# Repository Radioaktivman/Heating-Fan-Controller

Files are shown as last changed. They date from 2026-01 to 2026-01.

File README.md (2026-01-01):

# Heating Fan Controller

A temperature-controlled fan system for improving radiator efficiency through forced convection.

## Overview

This project provides an automated control system for heating radiator fans. By using forced convection, it significantly improves the heat output and efficiency of traditional radiators, especially at lower flow temperatures. This is particularly beneficial for heat pump systems that operate more efficiently at lower temperatures.

## Features

- **Temperature-Based Control**: Automatically activates fans based on radiator temperature
- **PWM Fan Control**: Smooth and quiet fan speed regulation
- **Efficient Heat Distribution**: Improves radiator efficiency and room heating
- **Low Noise Operation**: Designed for quiet residential use

## Why Use Radiator Fans?

Classical radiators typically require high flow temperatures to effectively heat a room. Adding forced convection with PC fans can:

- Significantly enhance radiator efficiency at low flow temperatures
- Enable heat pumps to operate at optimal (lower) temperatures
- Reduce heating costs while maintaining comfort
- Improve heat distribution in the room

### Advanced Monitoring and Control

With four temperature sensors, this controller provides comprehensive monitoring of the entire heating cycle:

- **Flow/Return Temperature Monitoring**: Track the temperature difference across the radiator to measure heat transfer efficiency
- **Air Temperature Delta**: Measure the temperature increase from inlet (bottom) to outlet (top) to quantify the actual heating effect
- **Performance Optimization**: Automatically adjust fan speed based on the temperature differentials to maximize efficiency
- **System Diagnostics**: Identify issues like poor circulation, air locks, or insufficient flow temperatures
- **Energy Efficiency**: Calculate the actual heat output and optimize fan operation to minimize electricity consumption while maximizing heat distribution

## Hardware Components

### Required Components
- **ESP Heating Controller PCB** (Rev 1.0 - design files in `/PCB` folder)
  - PCBs available from maintainer (contact via PM)
  - [3D-printable housing available on Thingiverse](https://www.thingiverse.com/thing:7254499)
- Temperature sensors: DS18B20 (up to 4 sensors supported)
- **12V PC fans** - Both 3-pin and 4-pin fans  up to 6 fans total
  - 3-pin fans: Standard DC voltage control
  - 4-pin PWM fans: Precise PWM speed control (recommended for quieter operation)
  - Note: All fans operate at the same speed (shared PWM signal)
- 12V power supply 
- **[3D-printed mounting clips](https://www.thingiverse.com/thing:5943925)** for attaching fans to radiators 

### Recommended Fans
High-quality PC fans operating at low speeds (<500 RPM) are essentially inaudible while providing significant heat output improvement. The controller supports both 3-pin and 4-pin fans.

## PCB Design

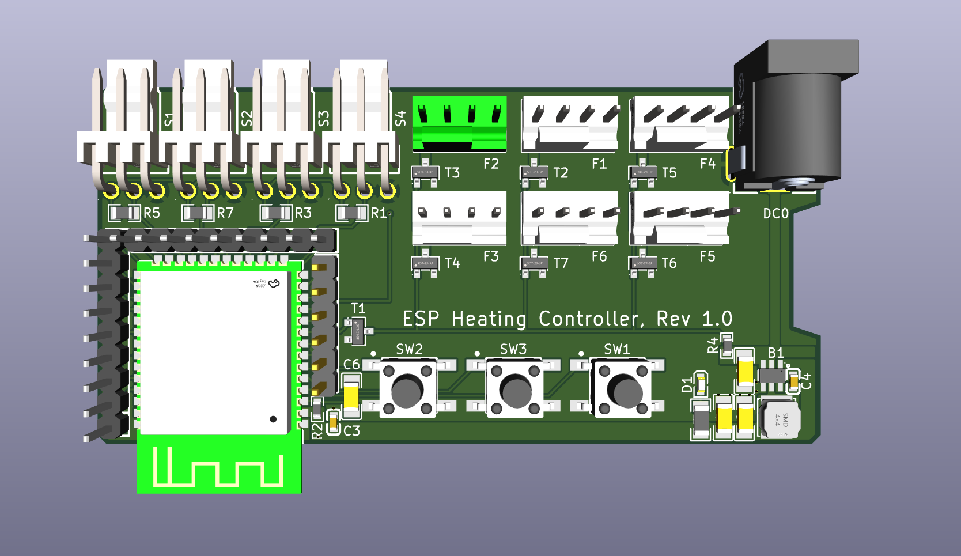
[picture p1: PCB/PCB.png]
ESP Heating Controller PCB

*ESP Heating Controller Rev 1.0 by 2SimpleEnergy GmbH*

The `/PCB` folder contains the custom PCB design files for this project. 

### Hardware Specifications

**Microcontroller:**
- ESP32-WROOM module (WiFi/Bluetooth enabled)
- Enables smart home integration and remote monitoring

**Fan Outputs:**
- **6 fan output channels** (F1-F6)
- **All channels share the same PWM control signal** - fans operate synchronously at the same speed
- Supports multiple fans or fan groups connected across the 6 outputs
- **Compatible with both 3-pin and 4-pin PC fans:**
  - **3-pin fans**: Standard DC voltage control (full voltage = full speed)
  - **4-pin PWM fans**: Advanced PWM control with tachometer feedback for precise speed regulation and RPM monitoring
- Standard 4-pin fan connectors for easy plug-and-play installation

**Temperature Sensor Inputs:**
- **3 Pin Connector ** (S1-S4) for DS18B20 or similar sensors
- Designed for comprehensive heating system monitoring:
  - **Flow temperature**: Monitor water entering the radiator
  - **Return flow temperature**: Monitor water leaving the radiator
  - **Air inlet temperature**: Measure air temperature at bottom of radiator (before heating)
  - **Air outlet temperature**: Measure air temperature at top of radiator (after heating)
- Pull-up resistors (R1, R3, R5, R7) integrated on board
- Enables precise control based on actual radiator performance and efficiency calculations

**User Interface:**
- 3 tactile buttons (SW1, SW2, SW3) for manual control and configuration
- Status LED indicators

**Power Supply:**
- DC barrel jack connector (DC0) for 12V input
- Onboard voltage regulation for ESP32 (3.3V)

**PCB Housing:**
A 3D-printable housing for this PCB is available on Thingiverse for protection and professional mounting:
👉 **[ESP Heating Controller PCB Housing](https://www.thingiverse.com/thing:7254499)**

**PCB Availability:**
I have some leftover PCBs ! If you're interested in procuring a board instead of manufacturing it yourself, please contact me via private message on GitHub.

## Installation

### Hardware Setup

1. **3D-print the components**:
   - Download and print the **[PCB housing](https://www.thingiverse.com/thing:7254499)** for the controller
   - Download and print the **[fan mounting clips](https://www.thingiverse.com/thing:5943925)** (2 clips per fan)
2. **Assemble the controller**:
   - Install the ESP Heating Controller PCB into the housing
   - Mount the housing to wall or heating
3. **Prepare the fans**: Mount the PC fans using the printed clips below your radiators
   - Insert clips from below between the radiator ribs
   - Ensure secure fit (designed for 75mm inner distance, adjustable)
   - Use cable ties through the eyelets for cable management
3. **Wire the temperature sensor**: Connect DS18B20 to the controller
   - Red: +3.3V 
   - Yellow/Data: Data line (with 4.7kΩ pull-up resistor)
   - Black: GND
3. **Connect the fans**: Wire fans to the controller output
4. **Power supply**: Connect 12V power supply

### Software Setup

1. Clone this repository:
```bash
git clone https://github.com/Radioaktivman/Heating-Fan-Controller.git
cd Heating-Fan-Controller
```

2. **Firmware Option: Tasmota**

This controller uses Tasmota firmware for easy configuration and smart home integration.

**Step-by-Step Tasmota Configuration:**

**Step 1: Flash Tasmota Firmware**
1. Flash Tasmota firmware to the ESP32 module using your preferred method (web flasher, esptool, etc.)
2. Select ESP32 variant during flashing

**Step 2: Initial WiFi Setup**
1. Power on the device - it will create a WiFi access point named "tasmota-XXXXXX"
2. Connect to this access point with your phone/computer
3. Configure your WiFi credentials:
   - SSID: YourNetworkName
   - Password: [Your WiFi Password]
4. The device will restart and connect to your network

**Step 3: Access Tasmota Web Interface**
1. Find the device's IP address (check your router or use Tasmota discovery)
2. Open a web browser and navigate to the IP address
3. You should see the Tasmota web interface

**Step 4: Configure Module Type**
1. Go to **Configuration** → **Configure Module**
2. Set **Module type** to **ESP32S3 (1)**
3. Click **Save** - the device will restart

**Step 5: Configure GPIO Pins**
After restart, go back to **Configuration** → **Configure Module** and set the following GPIO pins:

| GPIO Pin | Function | Number |
|---|---|---|
| GPIO03 | DS18x20 | 4 |
| GPIO04 | Button | 1 |
| GPIO05 | Button | 2 |
| GPIO06 | Button | 3 |
| GPIO11 | DS18x20 | 3 |
| GPIO14 | DS18x20 | 2 |
| GPIO16 | Relay_i | 1 |
| GPIO18 | PWM | 1 |
| GPIO48 | DS18x20 | 1 |

Leave all other GPIO pins set to **None**.

Click **Save** - the device will restart again.

**Step 6: Configure Temperature Sensor Names**
1. Go to **Console**
2. Enter the following commands to name your DS18B20 sensors:
```
Backlog DS18Alias 1,Flow; DS18Alias 2,Return; DS18Alias 3,AirIn; DS18Alias 4,AirOut
```

**Step 7: Configure Control Rules**
The three buttons provide manual control for the fan system. Configure the automation rules:

1. Go to **Console**
2. Enable Rule1:
```
Rule1 1
```
3. Configure Rule1 with the following logic:
```
Rule1 
ON Button3#state DO Dimmer + ENDON 
ON Button2#state DO Dimmer - ENDON 
ON Button1#state DO power1 toggle ENDON 
ON Dimmer#state >= 100 DO power1 off ENDON 
ON Dimmer#state < 80 DO power1 on ENDON
```

**Button Functions:**
- **Button 1 (GPIO04)**: Toggle fan power on/off
- **Button 2 (GPIO05)**: Decrease fan speed (Dimmer -)
- **Button 3 (GPIO06)**: Increase fan speed (Dimmer +)
- **Auto-control**: 
  - Fans turn OFF when dimmer reaches 100%
  - Fans turn ON when dimmer drops below 80%

**Step 8: Configure MQTT (Optional, for Home Assistant)**
1. Go to **Configuration** → **Configure MQTT**
2. Enter your MQTT broker details:
   - Host: [Your MQTT broker IP]
   - Port: 1883 (default)
   - Client: heating_controller_%06X
   - User: [Your MQTT username]
   - Password: [Your MQTT password]
   - Topic: heating_controller
3. Click **Save**

**Step 9: Test Your Setup**
1. Check that all four temperature sensors appear in the main interface
2. Test the three buttons for manual control
3. Verify PWM control is working by adjusting the dimmer
4. Monitor MQTT messages if configured

Your ESP Heating Controller is now fully configured and ready to use!

## Contributing

Contributions are welcome! Please feel free to submit a Pull Request or open an Issue for bugs, suggestions, or improvements.

## License

This project is licensed under the MIT License - see the [LICENSE](LICENSE) file for details.

## Acknowledgments

Inspired by similar projects in the home automation community focused on improving heating efficiency and reducing energy costs.

## Roadmap / TODO

### Upcoming Features

- **Thermostat Control Unit**: A thermostat control module will be added in the next update to gain full control of the heating system. This will enable:
  - Complete closed-loop heating control
  - Automatic heating system regulation based on flor and/or air temperature
  - Enhanced energy efficiency through intelligent heating management

## Contact

Project maintained by [@Radioaktivman](https://github.com/Radioaktivman)

---

**Note**: This is an early-stage project. Documentation and features will be expanded as development continues.

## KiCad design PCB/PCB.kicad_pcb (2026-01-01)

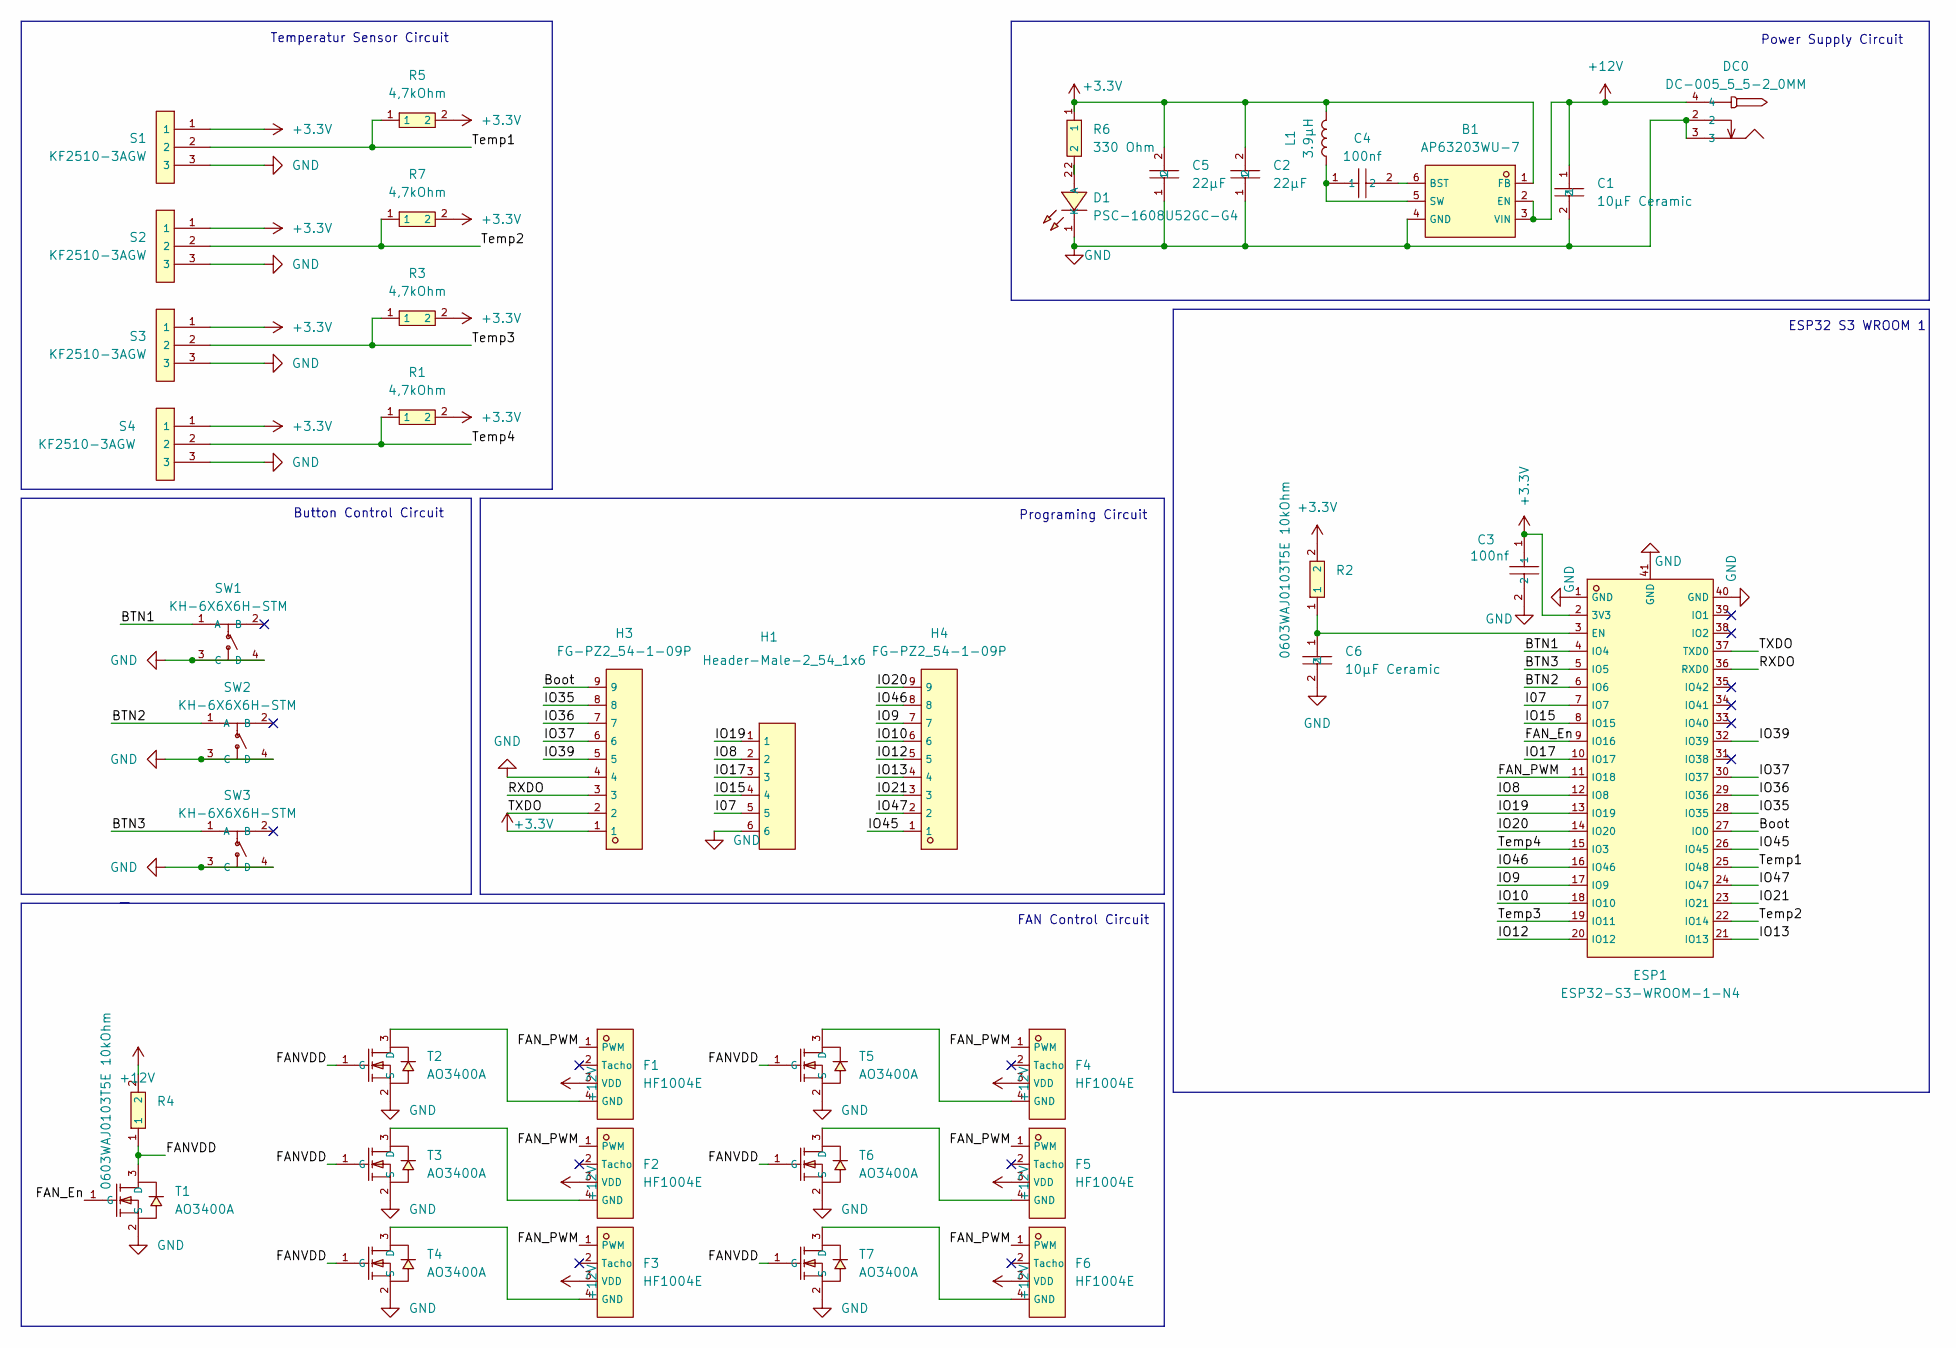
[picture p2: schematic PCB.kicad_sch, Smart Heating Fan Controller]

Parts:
B1: AP63203WU-7; TSOT-26_L2.9-W1.6-P0.95-LS2.8-BL; LCSC C780769
C1, C6: 10µF Ceramic; C1206; LCSC C13585
C2, C5: 22µF; C1206; LCSC C12891
C3, C4: 100nf; C0603; LCSC C1591
D1: PSC-1608U52GC-G4; LED0603-RD_GREEN; LCSC C22371297
DC0: DC-005_5_5-2_0MM; DC-IN-TH_DC-5520-1; LCSC C16214
ESP1: ESP32-S3-WROOM-1-N4; WIFIM-SMD_ESP32-S3-WROOM-1-N8; LCSC C2913197
F1, F2, F3, F4, F5, F6: HF1004E; CONN-TH_4P-P2.54_HF1004E; LCSC C2761402
H1: Header-Male-2_54_1x6; HDR-TH_6P-P2.54-V-M-1; LCSC C37208
H3, H4: FG-PZ2_54-1-09P; HDR-TH_9P-P2.54-V-M; LCSC C25687201
L1: 3.9µH; IND-SMD_L4.0-W4.0; LCSC C96899
R1, R3, R5, R7: 4,7kOhm; R0805; LCSC C17673
R2, R4: 0603WAJ0103T5E 10kOhm; R0603; LCSC C15401
R6: 330 Ohm; R1206; LCSC C25374
S1, S2, S3, S4: KF2510-3AGW; CONN-TH_KF2510-3AGW; LCSC C68663
SW1, SW2, SW3: KH-6X6X6H-STM; SW-SMD_4P-L6.0-W6.0-P4.50-LS9.0-3; LCSC C2837532
T1, T2, T3, T4, T5, T6, T7: AO3400A; SOT-23-3_L2.9-W1.3-P1.90-LS2.4-BR; LCSC C20917

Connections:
+3.3V: B1.1 (FB), C2.2, C3.1, C5.2, ESP1.2 (3V3), H3.1, L1.2, R1.2, R2.2, R3.2, R5.2, R6.1, R7.2, S1.1, S2.1, S3.1, S4.1
+12V: B1.2 (EN), B1.3 (VIN), C1.1, DC0.4, F1.3 (VDD), F2.3 (VDD), F3.3 (VDD), F4.3 (VDD), F5.3 (VDD), F6.3 (VDD), R4.2
/BTN1: ESP1.4 (IO4), SW1.1 (A)
/BTN2: ESP1.6 (IO6), SW2.1 (A)
/BTN3: ESP1.5 (IO5), SW3.1 (A)
/Boot: ESP1.27 (IO0), H3.9
/FANVDD: R4.1, T1.3 (D), T2.1 (G), T3.1 (G), T4.1 (G), T5.1 (G), T6.1 (G), T7.1 (G)
/FAN_En: ESP1.9 (IO16), T1.1 (G)
/FAN_PWM: ESP1.11 (IO18), F1.1 (PWM), F2.1 (PWM), F3.1 (PWM), F4.1 (PWM), F5.1 (PWM), F6.1 (PWM)
/I07: ESP1.7 (IO7), H1.5
/IO8: ESP1.12 (IO8), H1.2
/IO9: ESP1.17 (IO9), H4.7
/IO10: ESP1.18 (IO10), H4.6
/IO12: ESP1.20 (IO12), H4.5
/IO13: ESP1.21 (IO13), H4.4
/IO15: ESP1.8 (IO15), H1.4
/IO17: ESP1.10 (IO17), H1.3
/IO19: ESP1.13 (IO19), H1.1
/IO20: ESP1.14 (IO20), H4.9
/IO21: ESP1.23 (IO21), H4.3
/IO35: ESP1.28 (IO35), H3.8
/IO36: ESP1.29 (IO36), H3.7
/IO37: ESP1.30 (IO37), H3.6
/IO39: ESP1.32 (IO39), H3.5
/IO45: ESP1.26 (IO45), H4.1
/IO46: ESP1.16 (IO46), H4.8
/IO47: ESP1.24 (IO47), H4.2
/RXDO: ESP1.36 (RXD0), H3.3
/TXDO: ESP1.37 (TXD0), H3.2
/Temp1: ESP1.25 (IO48), R5.1, S1.2
/Temp2: ESP1.22 (IO14), R7.1, S2.2
/Temp3: ESP1.19 (IO11), R3.1, S3.2
/Temp4: ESP1.15 (IO3), R1.1, S4.2
GND: B1.4 (GND), C1.2, C2.1, C3.2, C5.1, C6.2, D1.1 (K), DC0.2, DC0.3, ESP1.1 (GND), ESP1.40 (GND), ESP1.41 (GND), H1.6, H3.4, S1.3, S2.3, S3.3, S4.3, SW1.3 (C), SW1.4 (D), SW2.3 (C), SW2.4 (D), SW3.3 (C), SW3.4 (D), T1.2 (S), T2.2 (S), T3.2 (S), T4.2 (S), T5.2 (S), T6.2 (S), T7.2 (S)
unnamed: B1.6 (BST), C4.2
unnamed: B1.5 (SW), C4.1, L1.1
unnamed: D1.2 (A), R6.2
unnamed: C6.1, ESP1.3 (EN), R2.1
unnamed: F1.4 (GND), T2.3 (D)
unnamed: F2.4 (GND), T3.3 (D)
unnamed: F3.4 (GND), T4.3 (D)
unnamed: F4.4 (GND), T5.3 (D)
unnamed: F5.4 (GND), T6.3 (D)
unnamed: F6.4 (GND), T7.3 (D)

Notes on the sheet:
Programing Circuit
Power Supply Circuit
Temperatur Sensor Circuit
ESP32 S3 WROOM 1
FAN Control Circuit
Button Control Circuit

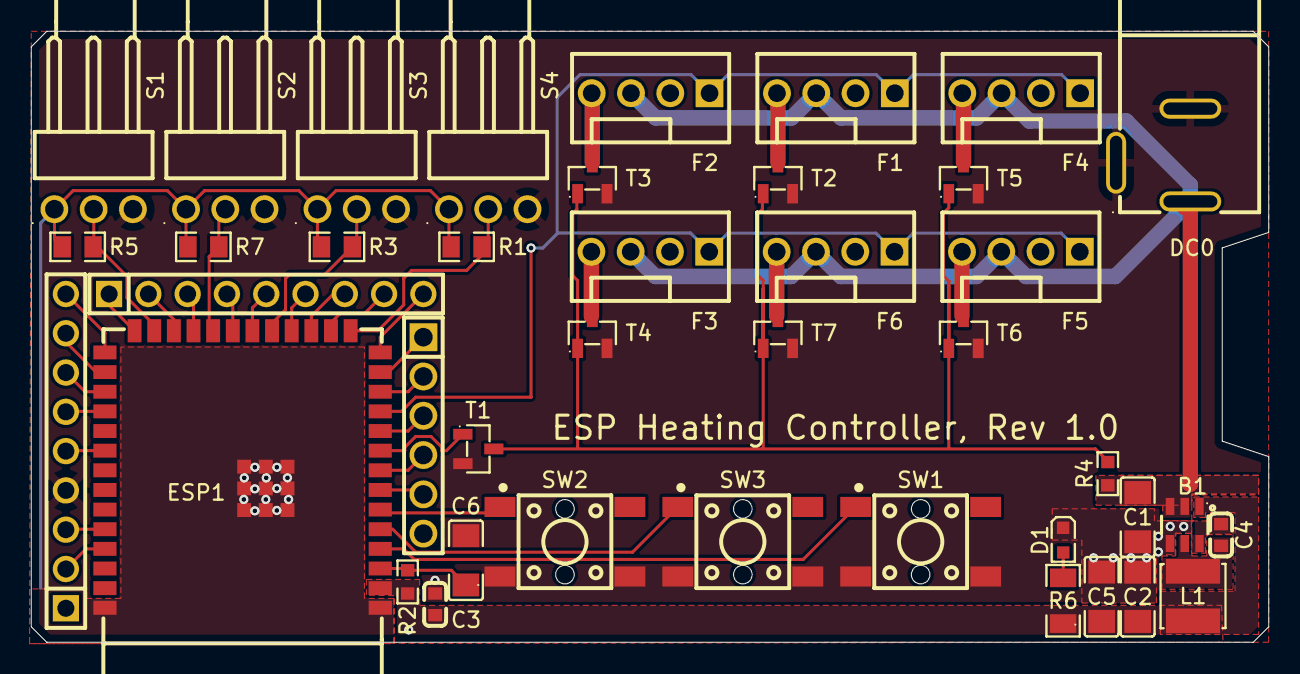
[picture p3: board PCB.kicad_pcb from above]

Board: 2 copper layers, 80.0 x 39.5 mm, 41 parts (0 on the bottom side), 44 nets.

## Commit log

2025-12-29 Uploaded Project Files
    [PCB.kicad_pcb, PCB.kicad_sch]
2025-12-29 added reference to housing thing on thingiverse
2026-01-01 Removed Company Name
    [PCB.kicad_pcb, PCB.kicad_sch]
